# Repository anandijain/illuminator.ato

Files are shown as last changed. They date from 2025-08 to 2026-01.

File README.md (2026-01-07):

# illuminator

[Onshape CAD](https://cad.onshape.com/documents/1effa1616a317fb48e7ffbf3/w/ae2fe78dc753e01a133967d8/e/a3ef25508ab919a74d42227d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)
[YouTube](https://youtube.com/playlist?list=PL79kqjVnD2ENzYDWSiDm63MTBGJOrp2XY&si=uE8JB_jzI9ln5rCQ)

petri dish illuminator for timelapses 

the functionality basically has an 
* mcu turn on a bunch of lights
* light goes thru a diffuser
* hit the petri (excite the fluorescent protein)
* into a filter 
* imaged via timelapse on a DSLR 

there are two modes to use the device
Common to both modes is using a GPIO pin to turn on a mosfet that turns on an LED grid. 

## Raspberry Pi Pico 
the first is using a raspberry pi pico, and the second is using a full fledged Pi. 
However, we still need to tell the camera to take a photo while the lights are on. 
The pico accomplishes this by using a GPIO pin to drive an optocoupler, which connects to the [MC-DC2](https://www.dslrbodies.com/cameras/general-nikon-camera-info/nikon-mc-dc2-connector-pin.html) port. 
Basically the opto provides a short between the Tip and the Sleeve, triggering a photo to be taken.

## Raspberry Pi 
Unfortunately, this method requires providing power for the board and the Pi separately (two power cables). 
Basically, a USB cable is connects the Pi to Nikon's semi-proprietary UC-E6 "USB" port. 
Then we use `gphoto2` to trigger the camera and download it to the Pi.

the design is as follows, a 5V 5A (5A is excessive, you probably dont need more than 2-3A) wall wart plugs to a barrel jack

the barrel jack tip will go to VBus of the USB port and the 36 resistor-led pairs (all parallel)

the ground of the barrel goes to the gnd of the USB. 

The usb is an TYPE-A connector that is used solely for powering the Pico (DO NOT USE FOR A FULL PI, the USB 2.0 spec is limited at 1.5A but a Pi can draw 5A.)

## pinouts 
There is a TRS (i dont like JST) port used for connecting GPIO from Pi/Pico to the board.
The Tip of `trs_sig` is only used by the pico, and is for turning on the optocoupler
The Ring is used by both for turning on the FET (the LEDs)
The Sleeve is GND. 

Note: on the TRS breakout cable, white is tip (pico w pin GP16), red is ring (pico w pin GP17), black is sleeve (pico w pin 23 (GND))

A second TRS connector is used to connect the MC-DC2 connector from camera to the optocoupler. Unfortunately, it seems common that MC-DC2 uses a 2.5mm TRS, but I am just going to use an adapter so that I don't need to buy 2.5mm jacks that I'll never use. 

The path is 5v -> (R -> LED)* -> FET_DRAIN -> FET_SOURCE -> GND.

## camera 
* make sure no autofocus is on cuz that increases the time to shorting the MC-DC2 to an unknown amount of time

## lcd
* to get mc_dc2_test/lcd.py to work you need to copy [this](https://github.com/russhughes/st7789py_mpy/blob/master/lib/st7789py.py) to /lib/ with `mpremote`

remember to also copy the fonts 

the interface of the lcd is three buttons, two are for incrementing and decrementing the timelapse parameters the third is for advancing to the next parameter

todo ui:
- see if its possible to start timelapse when both + and - are hit simultaneously or something

TODO before order:

Done:
* fix mounting holes position
* cad enclosure and box 
* order the diffuser and lens
*silkscreen art 

## board images (no kicad schematic see main.ato)
PCB
3D

## some BOM items
* [light diffuser](https://www.amazon.com/dp/B0818HYY8G)
* [hot plate for SMD soldering](https://www.amazon.com/dp/B082H12PPT)

### 8/28/25 

the general design will be relatively agnostic to the excitation wavelength, 
allowing multiple different proteins to be timelapsed 

TODO:
- resistor sizing for each string of LEDs
- can i PWM my N-mosfet that controls the leds? 

https://chatgpt.com/share/68b0b650-5c54-8009-a0fc-7b128db387fa

even though the excitation peak of [A. Victoria's GFP gene](https://www.fpbase.org/protein/avgfp/) is at 395 nm (UVA range), 
there is evidence that photobleaching occurs and can inhibit cell growth.

that, in addition to the eyes/skin risk of penetrating UV, we will use the weaker excitation peak of 
475 nm 

there are two primary routes to acheiving timelapses, 

the first is using a Pico and a port on the D7100 called MC-DC2 

the second is using a full RPi with gphoto2, this allows the collection of the photos onto the Pi

after extensive reading: the grid of LEDs will be 12 strings of 3 LEDs, powered by a 12V rail

maybe instead of a buck since it seems sparse to find preset 5V bucks at 3A (enought to power Pi)
and the ones that are adjustable seem annoying to implement

if we are going with the Pico, then its a bit easier since it's not going to need 5V 3A.

math

datasheet of led -> radiative flux (mW) -> photons/sec

concentration of GFP + QY + photons/sec -> number of emitted photons/sec

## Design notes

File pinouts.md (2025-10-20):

## buttons
from the left buttons numbered b1-b5 
all buttons use PULL UP
from right takes up GP0-4
the button gnd is on 

button board gnd <-> RPI8
b1 <-> GP4 RPI6
b2 <-> GP3 RPI5
b3 <-> GP2 RPI4
b4 <-> GP1 RPI2
b5 <-> GP0 RPI1

## LCD

bl <-> GP6 
rst <-> GP7
dc <-> GP8
cs <-> GP9
clk <-> GP10
din <-> GP11
gnd <-> RPI18
vcc <-> RPI 36

## pico <-> pcb
### trs
tip <-> GP26
ring <-> GP27
sleeve <-> GND (RPI 33)

### power (from the usb cable)
gnd <-> GND (RPI 38)
5v <-> VSYS (Rpi 39)

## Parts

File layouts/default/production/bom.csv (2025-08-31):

Designator | Footprint | Quantity | Value | LCSC Part #
C1 | C0805 | 1 |  | C49678
C2 | C1206 | 1 |  | C15008
CN1, CN2 | AUDIO-SMD_PJ-327A5JJ | 2 |  | C668605
DC1 | DC-IN-TH_DC-005-A200 | 1 |  | C720557
LED1, LED10, LED11, LED12, LED13, LED14, LED15, LED16, LED17, LED18, LED19, LED2, LED20, LED21, LED22, LED23, LED24, LED25, LED26, LED27, LED28, LED29, LED3, LED30, LED31, LED32, LED33, LED34, LED35, LED36, LED4, LED5, LED6, LED7, LED8, LED9 | LED0603-RD_BLUE | 36 |  | C965807
Q1 | SOT-23-3_L2.9-W1.3-P1.90-LS2.4-BR | 1 |  | C347475
R1 | R0805 | 1 |  | C95781
R10, R11, R12, R13, R14, R15, R16, R17, R18, R19, R20, R21, R22, R23, R24, R25, R26, R27, R28, R29, R30, R31, R32, R33, R34, R35, R36, R37, R38, R39, R4, R5, R6, R7, R8, R9 | R0805 | 36 |  | C114245
R2 | R0805 | 1 |  | C105577
R3 | R0805 | 1 |  | C2907217
U1 | SMD-4_L4.6-W6.5-P2.54-LS10.2-TL | 1 |  | C66405
USB1 | USB-A-SMD_USB-234-BCW | 1 |  | C720528

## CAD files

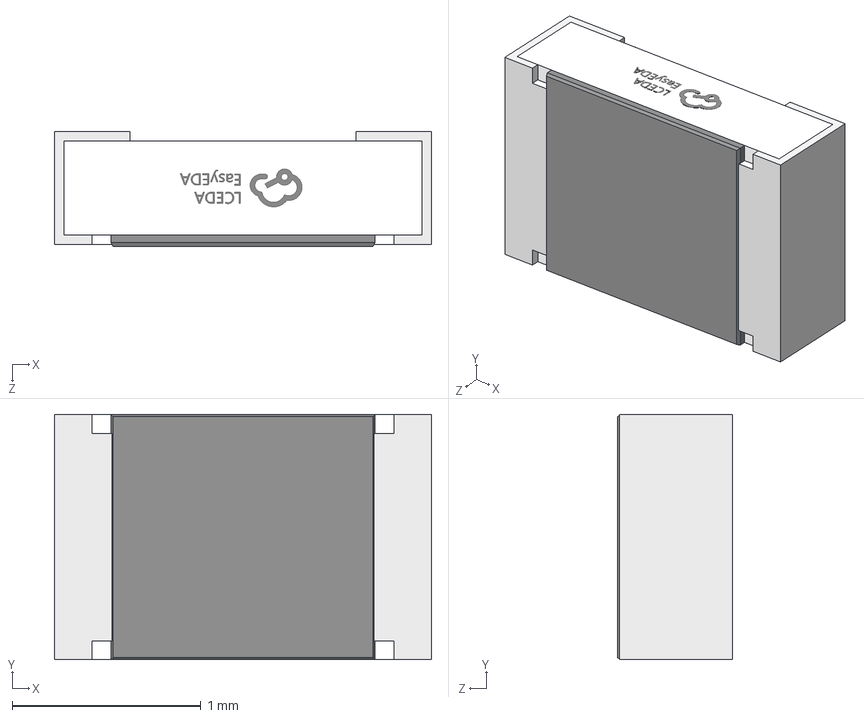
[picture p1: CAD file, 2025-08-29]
parts/FOJAN_FRC0805F1003TS/R0805_L2.0-W1.3-H0.6.step
2.00 x 1.30 x 0.61 mm

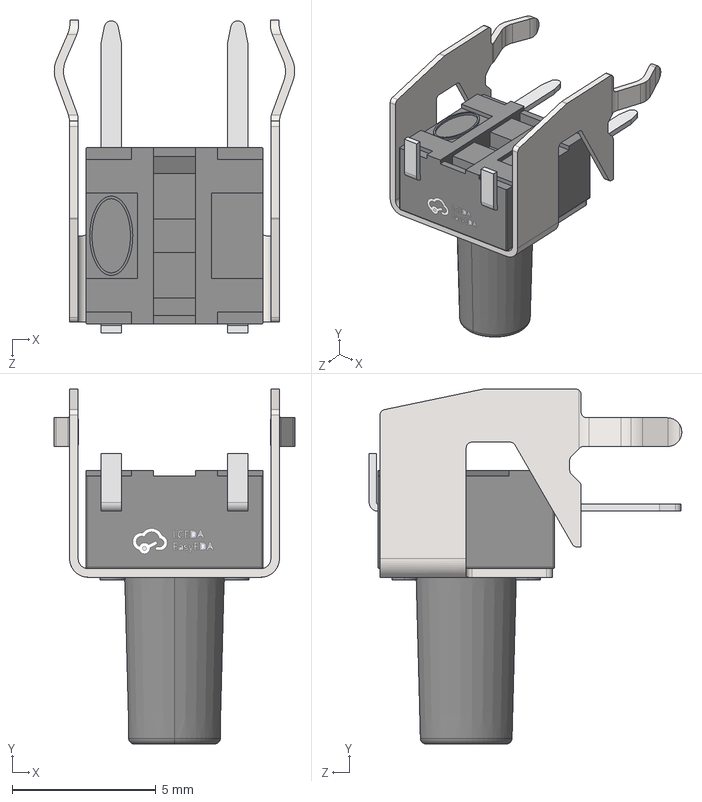
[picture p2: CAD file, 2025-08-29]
parts/HCTL_TC_6615_9_0_160G/KEY-TH_4P-L7.5-W8.4-H7.1-LS7.0-P4.5.step
8.37 x 12.4 x 10.9 mm

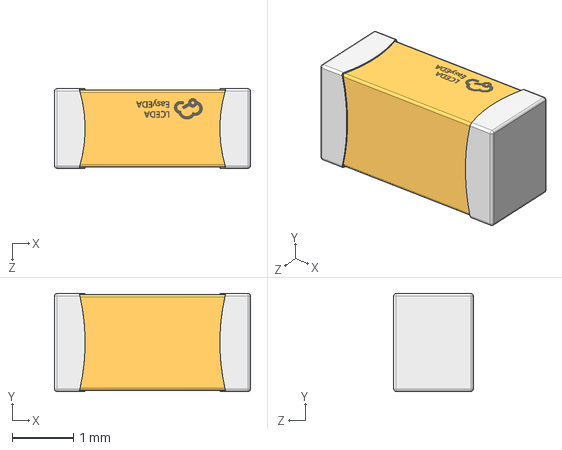
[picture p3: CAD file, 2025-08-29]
parts/Samsung_Electro_Mechanics_CL31A107MQHNNNE/C1206_L3.2-W1.6-H1.3.step
3.20 x 1.60 x 1.30 mm

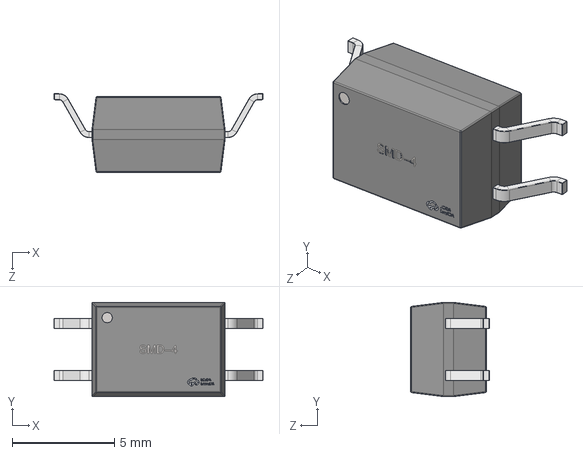
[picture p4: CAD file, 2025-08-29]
parts/Sharp_Microelectronics_PC817X2CSP9F/SMD-4_L4.6-W6.5-H3.7-LS10.2-P2.54.step
10.2 x 4.60 x 3.85 mm

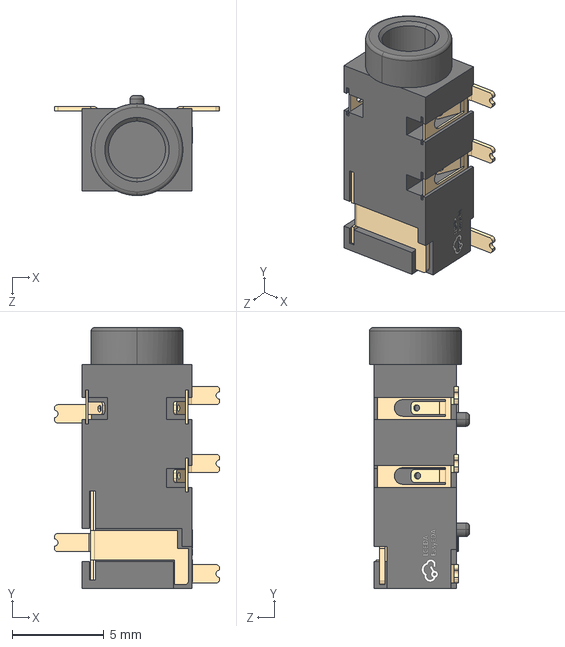
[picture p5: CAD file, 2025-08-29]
parts/SHOU_HAN_PJ_327A_5JJ/AUDIO-SMD_PJ-327A5JJ.step
9.00 x 14.2 x 5.45 mm

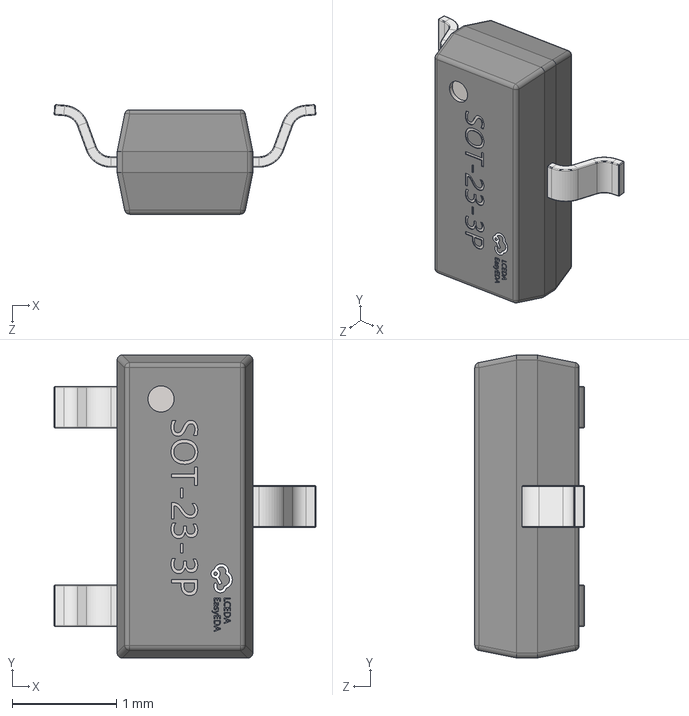
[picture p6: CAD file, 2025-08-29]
parts/UMW_AO3400A/SOT-23-3P_L2.9-W1.3-H1.0-LS2.4-P0.95.step
2.51 x 2.90 x 1.05 mm

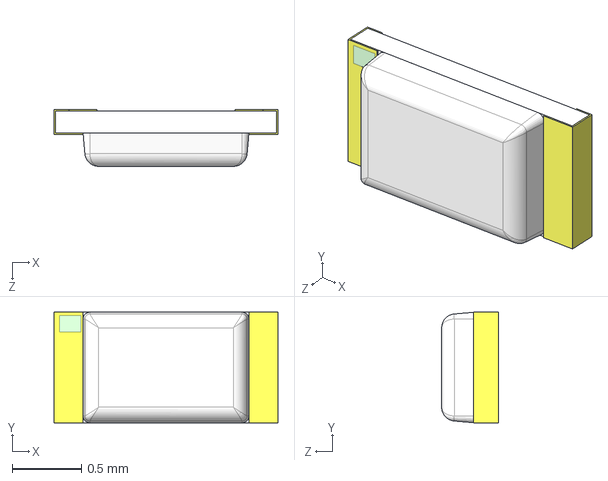
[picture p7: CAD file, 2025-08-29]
parts/XINGLIGHT_XL_1608UBC_04/LED0603-RD_BLUE.STEP
1.62 x 0.8 x 0.41 mm

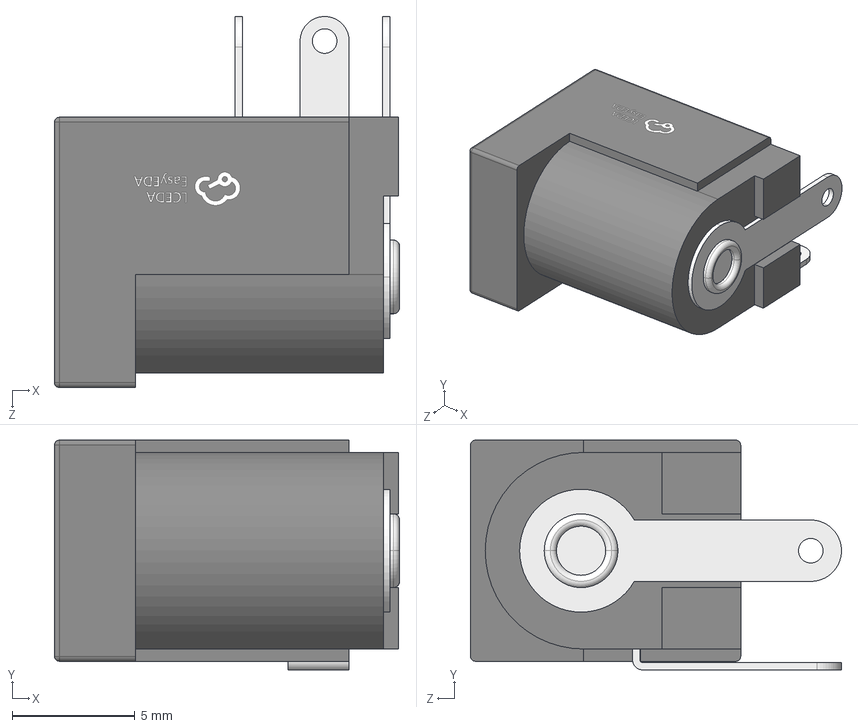
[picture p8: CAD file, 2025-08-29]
parts/XUNPU_DC_005_A200/DC-IN-TH_DC-005-A200.STEP
14.1 x 9.35 x 15.1 mm

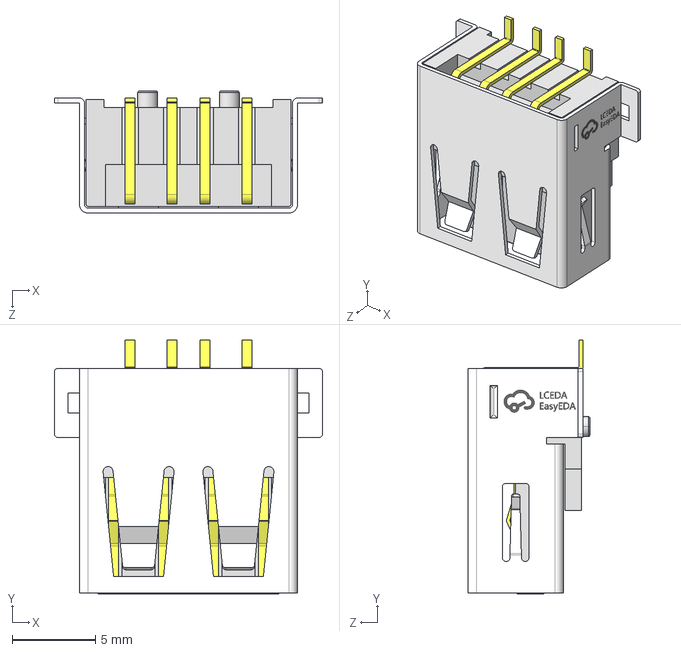
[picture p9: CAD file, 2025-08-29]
parts/XUNPU_USB_234_BCW/USB-A-SMD_USB-234-BCW.step
16.1 x 15.2 x 7.32 mm

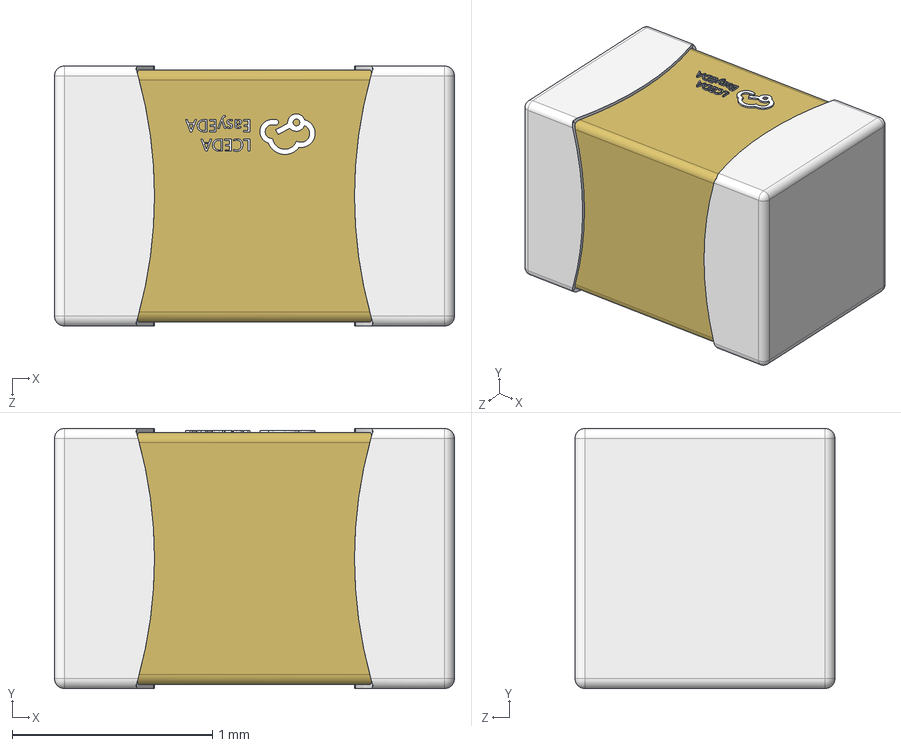
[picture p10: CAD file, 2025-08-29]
parts/YAGEO_CC0805KRX7R9BB104/C0805_L2.0-W1.3-H1.3.step
2.00 x 1.30 x 1.30 mm

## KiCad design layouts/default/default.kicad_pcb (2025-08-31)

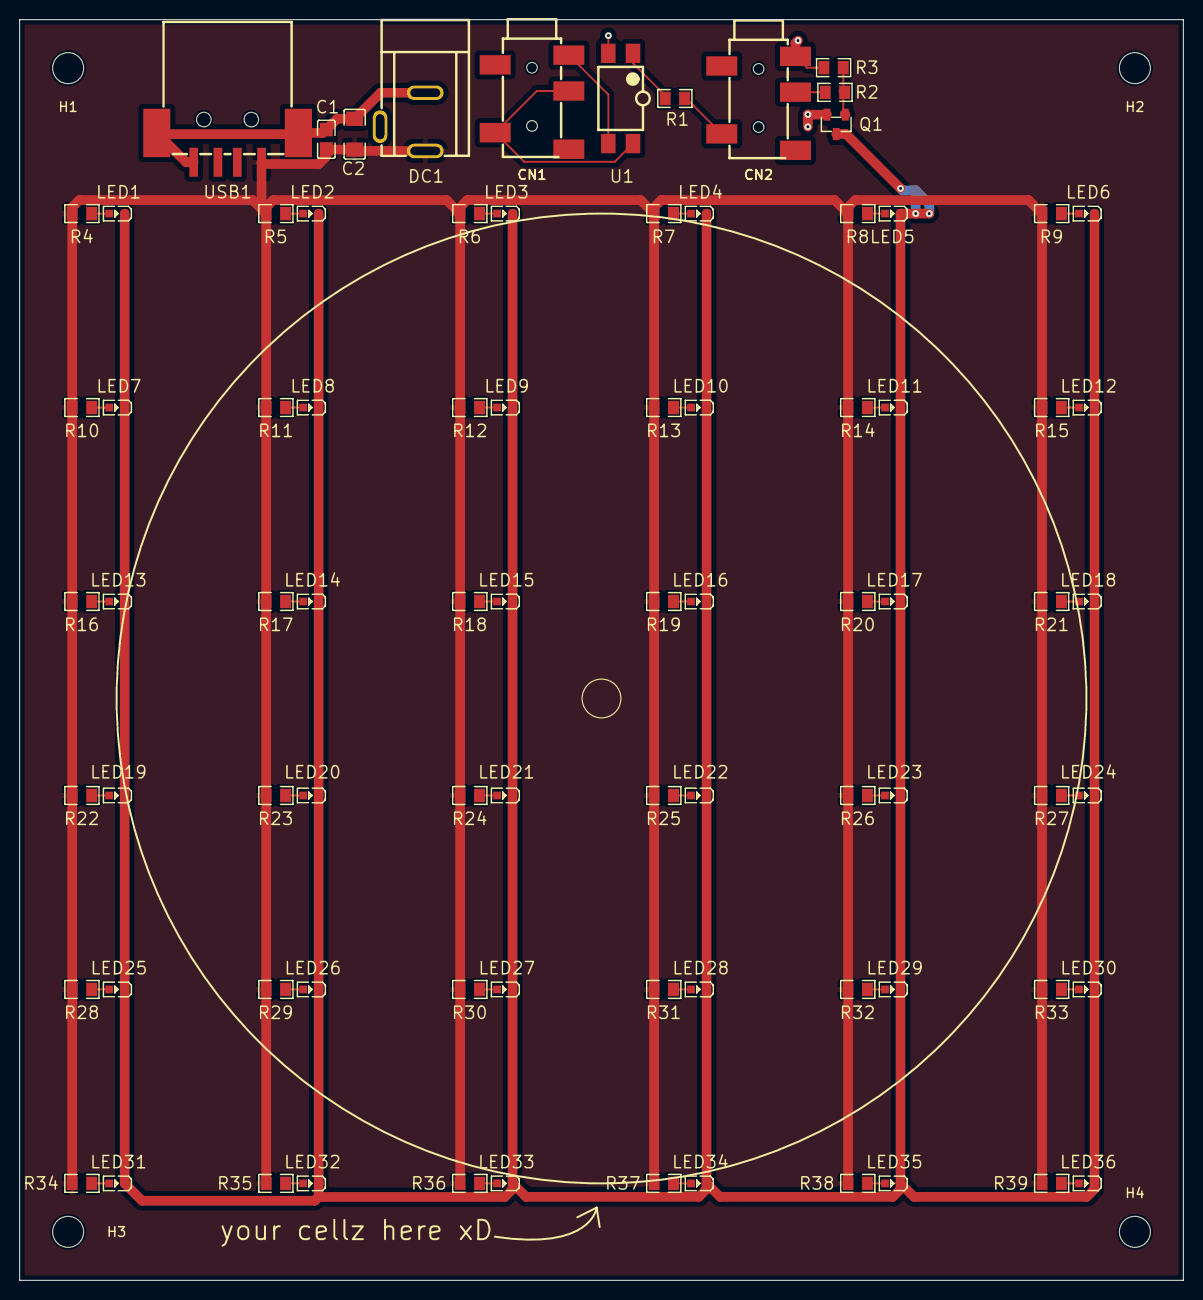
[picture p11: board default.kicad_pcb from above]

Board: 2 copper layers, 120.0 x 130.0 mm, 87 parts (0 on the bottom side), 45 nets.

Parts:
C1: C0805
C2: C1206
CN1, CN2: AUDIO-SMD_PJ-327A5JJ
DC1: DC-IN-TH_DC-005-A200
H1, H2, H3, H4: MountingHole_3.2mm_M3
LED1, LED2, LED3, LED4, LED5, LED6, LED7, LED8, LED9, LED10, LED11, LED12, LED13, LED14, LED15, LED16, LED17, LED18, LED19, LED20, LED21, LED22, LED23, LED24, LED25, LED26, LED27, LED28, LED29, LED30, LED31, LED32, LED33, LED34, LED35, LED36: LED0603-RD_BLUE
Q1: SOT-23-3_L2.9-W1.3-P1.90-LS2.4-BR
R1, R2, R3, R4, R5, R6, R7, R8, R9, R10, R11, R12, R13, R14, R15, R16, R17, R18, R19, R20, R21, R22, R23, R24, R25, R26, R27, R28, R29, R30, R31, R32, R33, R34, R35, R36, R37, R38, R39: R0805
U1: SMD-4_L4.6-W6.5-P2.54-LS10.2-TL
USB1: USB-A-SMD_USB-234-BCW

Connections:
G: Q1.1, R2.2, R3.1
GND: C1.2, C2.2, CN2.1, DC1.2, Q1.2, R3.2, U1.2, USB1.4, USB1.5, USB1.6
K: LED1.1, LED2.1, LED3.1, LED4.1, LED5.1, LED6.1, LED7.1, LED8.1, LED9.1, LED10.1, LED11.1, LED12.1, LED13.1, LED14.1, LED15.1, LED16.1, LED17.1, LED18.1, LED19.1, LED20.1, LED21.1, LED22.1, LED23.1, LED24.1, LED25.1, LED26.1, LED27.1, LED28.1, LED29.1, LED30.1, LED31.1, LED32.1, LED33.1, LED34.1, LED35.1, LED36.1, Q1.3
S: CN1.1, U1.3
T: CN2.4, R1.1
VCC: C1.1, C2.1, DC1.1, R4.1, R5.1, R6.1, R7.1, R8.1, R9.1, R10.1, R11.1, R12.1, R13.1, R14.1, R15.1, R16.1, R17.1, R18.1, R19.1, R20.1, R21.1, R22.1, R23.1, R24.1, R25.1, R26.1, R27.1, R28.1, R29.1, R30.1, R31.1, R32.1, R33.1, R34.1, R35.1, R36.1, R37.1, R38.1, R39.1, USB1.1
_1: R1.2, U1.1
footprint-A-0: LED1.2, R4.2
footprint-A-1: LED11.2, R14.2
footprint-A-2: LED12.2, R15.2
footprint-A-3: LED13.2, R16.2
footprint-A-4: LED14.2, R17.2
footprint-A-5: LED15.2, R18.2
footprint-A-6: LED16.2, R19.2
footprint-A-7: LED17.2, R20.2
footprint-A-8: LED18.2, R21.2
footprint-A-9: LED19.2, R22.2
footprint-A-10: LED20.2, R23.2
footprint-A-11: LED2.2, R5.2
footprint-A-12: LED21.2, R24.2
footprint-A-13: LED22.2, R25.2
footprint-A-14: LED23.2, R26.2
footprint-A-15: LED24.2, R27.2
footprint-A-16: LED25.2, R28.2
footprint-A-17: LED26.2, R29.2
footprint-A-18: LED27.2, R30.2
footprint-A-19: LED28.2, R31.2
footprint-A-20: LED29.2, R32.2
footprint-A-21: LED30.2, R33.2
footprint-A-22: LED3.2, R6.2
footprint-A-23: LED31.2, R34.2
footprint-A-24: LED32.2, R35.2
footprint-A-25: LED33.2, R36.2
footprint-A-26: LED34.2, R37.2
footprint-A-27: LED35.2, R38.2
footprint-A-28: LED36.2, R39.2
footprint-A-29: LED4.2, R7.2
footprint-A-30: LED5.2, R8.2
footprint-A-31: LED6.2, R9.2
footprint-A-32: LED7.2, R10.2
footprint-A-33: LED8.2, R11.2
footprint-A-34: LED9.2, R12.2
footprint-A-35: LED10.2, R13.2
footprint-R-0: CN1.3, CN1.4, U1.4
footprint-R-1: CN2.3, R2.1

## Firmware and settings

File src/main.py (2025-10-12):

from machine import Pin, SPI, PWM
import time
import st7789py as st7789
# import vga1_8x8 as font
# import vga1_16x16 as font
import vga2_16x32 as font
import math

def on_off(p, delay=0.1):
    p.value(1)
    time.sleep(delay)
    p.value(0)
    time.sleep(delay)

def snap():
    # Example: gate power on, pulse opto, gate off
    FET_PIN.value(1)
    on_off(OPTO_PIN, delay=0.2)
    FET_PIN.value(0)
    LED.toggle()  # visual heartbeat

def timelapse(interval, duration):
    global running
    running = True

    if duration == "forever":
        next_t = time.ticks_ms()
        while running:
            snap()
            next_t = time.ticks_add(next_t, int(interval * 1000))
            time.sleep_ms(max(0, time.ticks_diff(next_t, time.ticks_ms())))
        return  # exit when running is cleared

    dur_sec = duration * 3600
    num_snaps = math.ceil(dur_sec / interval)

    next_t = time.ticks_ms()
    for i in range(num_snaps):
        if not running:
            break  # early stop
        snap()
        if i == num_snaps - 1:
            break
        next_t = time.ticks_add(next_t, int(interval * 1000))
        time.sleep_ms(max(0, time.ticks_diff(next_t, time.ticks_ms())))
    running = False  # finished

def draw():
    for i, key in enumerate(param_keys):
        prefix = "> " if i == cursor_idx else "  "
        tft.text(font, "{}{}: {}".format(prefix, key, params[key]), 0, i*font.HEIGHT)

def incr_cb(p):
    global change_delta
    change_delta += 1     # simple integer change is safe

def decr_cb(p):
    global change_delta
    change_delta -= 1

def next_cb(p):
    global next_pending
    next_pending = True

def start_cb(p):
    global start_pending, running
    if running:
        # request stop
        running = False
        tft.text(font, "stopping timelapse...", 0, (N_PARAMS+1)*font.HEIGHT)
    else:
        start_pending = True  # request start


OPTO_PIN = Pin(16, Pin.OUT)
FET_PIN  = Pin(17, Pin.OUT)
LED      = Pin("LED", Pin.OUT)
OPTO_PIN.off()
FET_PIN.off()

spi = SPI(1, baudrate=40_000_000, polarity=0, phase=0,
          sck=Pin(10), mosi=Pin(11))
dc  = Pin(8,  Pin.OUT)
cs  = Pin(9,  Pin.OUT)
rst = Pin(12, Pin.OUT)

bl = PWM(Pin(13)); bl.freq(1000); bl.duty_u16(65535)

decr = Pin(21, Pin.IN, Pin.PULL_UP)
incr = Pin(20, Pin.IN, Pin.PULL_UP)
next = Pin(19, Pin.IN, Pin.PULL_UP)
start = Pin(18, Pin.IN, Pin.PULL_UP)

params = {"interval [s]": 5, "duration [hr]": 10}
param_keys = list(params)
N_PARAMS = len(params)


tft = st7789.ST7789(spi, 240, 320, reset=rst, dc=dc, cs=cs, rotation=1)
tft.fill(st7789.RED)

cursor_idx = 0

draw()

change_delta = 0   # -1, 0, +1 pending changes for current field
next_pending = False
start_pending = False
running = False

decr.irq(trigger=Pin.IRQ_RISING, handler=decr_cb)
incr.irq(trigger=Pin.IRQ_RISING, handler=incr_cb)
next.irq(trigger=Pin.IRQ_RISING, handler=next_cb)
start.irq(trigger=Pin.IRQ_RISING, handler=start_cb)

last_apply = time.ticks_ms()
APPLY_EVERY_MS = 100   # small debounce / coalesce window

while True:
    try: 
        now = time.ticks_ms()

        # handle "next" (change selected field)
        if next_pending:
            next_pending = False
            cursor_idx = (cursor_idx + 1) % N_PARAMS
            draw()
        if start_pending:
            start_pending = False
            if not running:
                tft.text(font, "starting timelapse...", 0, (N_PARAMS+1)*font.HEIGHT)
                timelapse(params["interval [s]"], params["duration [hr]"])
        # coalesce +/- presses and apply periodically (debounce-ish)
        if change_delta != 0 and time.ticks_diff(now, last_apply) >= APPLY_EVERY_MS:
            key = param_keys[cursor_idx]
            params[key] += change_delta
            change_delta = 0
            last_apply = now
            draw()

        time.sleep_ms(5)
    except KeyboardInterrupt:
        break

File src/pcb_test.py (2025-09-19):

from machine import Pin
import time
import math

OPTO_PIN = Pin(16, Pin.OUT)
FET_PIN  = Pin(17, Pin.OUT)
LED      = Pin("LED", Pin.OUT)

def on_off(p, delay=0.1):
    p.value(1)
    time.sleep(delay)
    p.value(0)
    time.sleep(delay)

def snap():
    # Example: gate power on, pulse opto, gate off
    FET_PIN.value(1)
    on_off(OPTO_PIN, delay=0.3)
    FET_PIN.value(0)
    LED.toggle()  # visual heartbeat

def timelapse(interval, duration):
    """
    interval: seconds between snaps (float ok)
    duration: total run time in HOURS, or the string "forever"
    """
    if duration == "forever":
        next_t = time.ticks_ms()
        while True:
            snap()
            next_t = time.ticks_add(next_t, int(interval * 1000))
            time.sleep_ms(max(0, time.ticks_diff(next_t, time.ticks_ms())))
        # never returns

    dur_sec = duration * 3600  # duration is in HOURS per docstring
    num_snaps = math.ceil(dur_sec / interval)

    next_t = time.ticks_ms()
    for i in range(num_snaps):
        snap()
        if i == num_snaps - 1:
            break  # don't sleep after last snap
        next_t = time.ticks_add(next_t, int(interval * 1000))
        time.sleep_ms(max(0, time.ticks_diff(next_t, time.ticks_ms())))

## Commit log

2025-08-29 nearing v1
    [AUDIO-SMD_PJ-327A5JJ.step, DC-IN-TH_DC-005-A200.STEP, KEY-TH_4P-L7.5-W8.4-H7.1-LS7.0-P4.5.step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]
2025-08-29 decoupling caps
    [C0805_L2.0-W1.3-H1.3.step, C1206_L3.2-W1.6-H1.3.step]
2025-08-29 dont even know whats up w the max current thing
    [default.kicad_pcb]
2025-08-30 vibe coded garbage to try to get the pcb to not have duplicate refdes
    at least a rough draft of the pcb is done tho
    the current workflow is
    delete everything on pcb, save, ato build, uv run old.py, open kicad, then manually delete the extras, and move the remaining refdes and layout route as normal.
    [default.kicad_pcb]
2025-08-30 gerbers, mounting holes, gnd and vcc fills
    [default.kicad_pcb]
2025-08-30 besides mounting holes, the pcb is almost there
    [default.kicad_pcb]
2025-08-30 just manually do mounting holes since the people at atopile are LYING to me
    [default.kicad_pcb]
2025-08-30 silkscreen bug
    [default.kicad_pcb]
2025-08-31 how could i forget the silkscreen art??
    [default.kicad_pcb]
2025-08-31 the camera only takes pictures if BOTH the Ring and Tip are shorted to ground. so we add a connection on board from R ~ T
    have not changed layout/routing yet
2025-08-31 add the T ~ R trace, redo the fill zone and rebuild the gerbers
    [default.kicad_pcb]
2025-08-31 address some DFM warnings and errors
    supposedly i fixed these:
    * soldermask opening exposing trace (1)
    * at least some of the "silkscreen to pad" errors
    * silkscreen to hole
    * annular ring warnings, changed via diam to .7 ( should also improve thermals a bit)
    [default.kicad_pcb]
2025-08-31 fix a dfm error about placing a via directly under a pad (lead to hole distance)
    [default.kicad_pcb]
2025-08-31 unignore the bom + pos. reexport step file
    [bom.csv, designators.csv, positions.csv]
2025-09-19 notes and pcb test code
2025-09-19 screen test works and untested timelapse code written for the pcb_test
2026-01-07 hot plate in bom
